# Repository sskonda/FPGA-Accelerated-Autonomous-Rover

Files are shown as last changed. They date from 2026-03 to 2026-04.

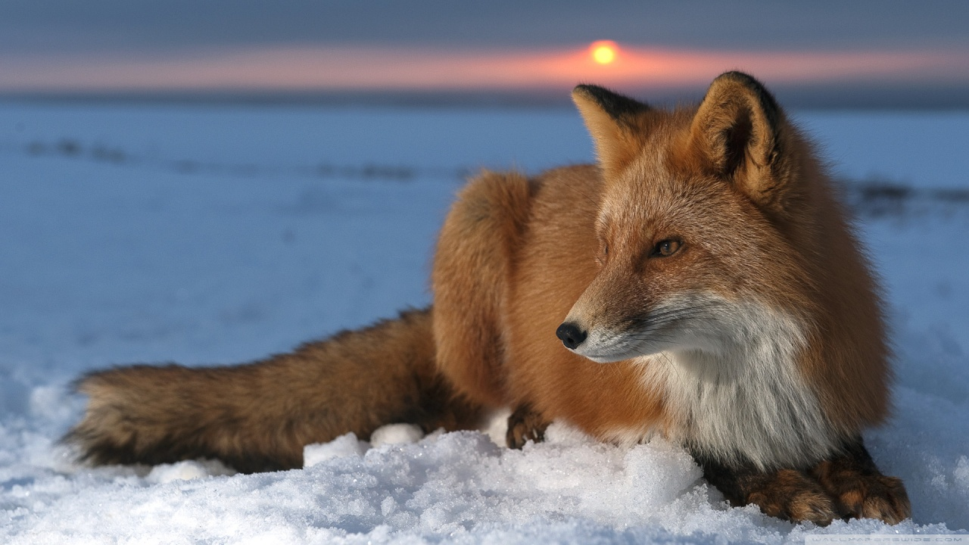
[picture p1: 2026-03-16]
vivado-library-master/ip/video_scaler/hls_src/test/fox.bmp

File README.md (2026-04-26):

# FPGA-Accelerated-Autonomous-Rover

Autonomous FPGA-based mobile robot that follows lanes, detects obstacles, monitors system telemetry, locates a charging dock, and demonstrates wireless charging behavior using a Zynq-based FPGA SoC.

This project is also referred to as **ERN**: **FPGA-Based Electronic Rechargeable Navigator**.

## Table of Contents

- [Project Purpose](#project-purpose)
- [Problem Being Addressed](#problem-being-addressed)
- [Project Overview](#project-overview)
- [Why an SoC Instead of a Microcontroller, Raspberry Pi, or Jetson?](#why-an-soc-instead-of-a-microcontroller-raspberry-pi-or-jetson)
  - [Compared to a Microcontroller](#compared-to-a-microcontroller)
  - [Compared to a Raspberry Pi](#compared-to-a-raspberry-pi)
  - [Compared to a Jetson](#compared-to-a-jetson)
  - [Why the SoC Approach Fits This Rover Best](#why-the-soc-approach-fits-this-rover-best)
  - [Platform Comparison](#platform-comparison)
  - [The Main Engineering Point](#the-main-engineering-point)
  - [Why This Makes the Project More Impressive](#why-this-makes-the-project-more-impressive)
- [Main System Capabilities](#main-system-capabilities)
  - [Implemented or Integrated](#implemented-or-integrated)
  - [Planned or Demonstrated Behavior](#planned-or-demonstrated-behavior)
- [System Architecture](#system-architecture)
- [Hardware/Software Partitioning](#hardwaresoftware-partitioning)
- [Hardware Platform](#hardware-platform)
  - [Main Compute Platform](#main-compute-platform)
  - [Robot Chassis and Drive System](#robot-chassis-and-drive-system)
  - [Sensors and Peripherals](#sensors-and-peripherals)
- [Vivado FPGA Design](#vivado-fpga-design)
- [Embedded Software Architecture](#embedded-software-architecture)
  - [FreeRTOS Task Model](#freertos-task-model)
- [Camera and Video Pipeline](#camera-and-video-pipeline)
- [Line-Following Algorithm](#line-following-algorithm)
  - [HDMI Debug Overlay](#hdmi-debug-overlay)
- [Custom Motor-Control IP](#custom-motor-control-ip)
  - [Register Map](#register-map)
  - [Control Bit Layout](#control-bit-layout)
  - [Differential Drive Usage](#differential-drive-usage)
- [Sensor Integration](#sensor-integration)
  - [BNO055 IMU](#bno055-imu)
  - [INA260 Power Monitor](#ina260-power-monitor)
  - [MAXSONAR Obstacle Sensor](#maxsonar-obstacle-sensor)
- [Obstacle Detection and Safe Stop](#obstacle-detection-and-safe-stop)
- [Audio Feedback System](#audio-feedback-system)
- [Power Monitoring and Wireless Charging](#power-monitoring-and-wireless-charging)
- [Repository Structure](#repository-structure)
- [Important Source Files](#important-source-files)
- [Build Environment](#build-environment)
- [Bring-Up and Test Strategy](#bring-up-and-test-strategy)
  - [1. Video Only](#1-video-only)
  - [2. Motor IP Only](#2-motor-ip-only)
  - [3. BNO055 Only](#3-bno055-only)
  - [4. INA260 Only](#4-ina260-only)
  - [5. Sonar Only](#5-sonar-only)
  - [6. Audio Only](#6-audio-only)
  - [7. FreeRTOS Integration](#7-freertos-integration)
  - [8. Full Robot Test](#8-full-robot-test)
- [Typical UART Output](#typical-uart-output)
- [Engineering Challenges and Fixes](#engineering-challenges-and-fixes)
  - [Camera Pipeline Bring-Up](#camera-pipeline-bring-up)
  - [Vitis and xparameters.h Compatibility](#vitis-and-xparametersh-compatibility)
  - [FreeRTOS and Interrupt Conflicts](#freertos-and-interrupt-conflicts)
  - [Sensor Initialization Blocking](#sensor-initialization-blocking)
  - [UART Logging From Multiple Tasks](#uart-logging-from-multiple-tasks)
  - [Audio Integration](#audio-integration)
  - [Motor Control and Duty Tuning](#motor-control-and-duty-tuning)
- [Current Status](#current-status)
- [Known Limitations](#known-limitations)
- [Future Work](#future-work)
- [Skills Demonstrated](#skills-demonstrated)
- [Team](#team)
- [Project Summary](#project-summary)

## Project Purpose

The purpose of this project is to design and build a small-scale autonomous guided vehicle that demonstrates the value of **FPGA-based real-time control** in an embedded robotics system.

The rover is designed to behave like a simplified autonomous mobile robot used in warehouse, factory, or material-handling environments. It must detect a visual path on the ground, follow that path, stop safely when an obstacle is present, monitor its own electrical state, and eventually navigate toward a charging station when battery level is low.

The important part of this project is not only that the robot can move. The main purpose is to demonstrate a complete **hardware/software co-design** approach:

- Real-time camera and video infrastructure is handled using FPGA-oriented hardware blocks.
- Motor timing is generated deterministically using custom programmable logic.
- High-level behavior, telemetry, task scheduling, and control decisions run on the ARM processor.
- FreeRTOS coordinates multiple concurrent robot subsystems.
- Power, sensing, actuation, perception, audio, and charging are integrated into one platform.

This makes the project more than a basic robotics demo. It is a complete embedded SoC system that combines computer vision, FPGA logic, real-time software, custom hardware IP, sensor integration, and power electronics.

## Problem Being Addressed

Repetitive material-handling tasks in warehouses and factories are commonly automated using autonomous guided vehicles or autonomous mobile robots. These robots transport materials along predefined routes, avoid obstacles, and return to charging stations when power is low.

Many small autonomous robots are built around software-centric platforms such as Raspberry Pi boards, Jetson modules, or microcontrollers. Those platforms are flexible and easy to prototype with, but they often push every major subsystem through software. Camera processing, motor control, telemetry, obstacle detection, audio, and decision logic all compete for CPU time, memory bandwidth, and operating-system scheduling.

That creates several problems:

- **Higher latency** for time-sensitive camera and control tasks
- **Less predictable timing** when multiple software tasks run at once
- **Higher power usage** compared to dedicated hardware logic
- **More CPU contention** between vision, telemetry, control, and I/O
- **Less deterministic motor control** when PWM generation depends on software timing
- **Reduced scalability** when adding more sensors, actuators, or perception features

This project explores a different approach: use an FPGA SoC to separate the system into hardware tasks and software tasks. The FPGA fabric handles deterministic and timing-sensitive work, while the ARM processor handles high-level system behavior.

## Project Overview

The FPGA-Accelerated Autonomous Rover is built around the **Digilent Zybo Z7-20**, which contains a **Xilinx Zynq-7000 SoC**. The Zynq device combines an ARM Cortex-A9 processing system with FPGA programmable logic on the same chip.

The rover uses:

- A **PCam 5C camera** for visual lane detection
- A **Zybo Z7-20 FPGA SoC** for video, control, and peripheral integration
- A **custom AXI4-Lite motor-control IP** for deterministic PWM generation
- A **BNO055 IMU** for motion telemetry and navigation experiments
- An **INA260 power monitor** for voltage/current/power telemetry
- A **MAXSONAR ultrasonic range sensor** for obstacle detection
- The **Zybo onboard SSM2603 audio codec** for audio feedback
- A **wireless charging dock** to demonstrate autonomous recharging behavior

The robot's intended behavior is:

1. Boot the FPGA and embedded software.
2. Initialize the camera, video pipeline, motor IP, sensors, sonar, telemetry, and optional audio.
3. Display live camera output over HDMI.
4. Detect a tape-based lane in the camera frame.
5. Compute the lane center relative to the image center.
6. Adjust left and right motor duty cycles to keep the lane centered.
7. Stop or brake if an obstacle is detected.
8. Monitor battery voltage/current.
9. Navigate toward a charging location or dock when required.
10. Demonstrate wireless charging by measuring a voltage/current increase at the charging location.

## Why an SoC Instead of a Microcontroller, Raspberry Pi, or Jetson?

A major purpose of this project was to demonstrate why a **System-on-Chip FPGA platform** is valuable for real-time embedded robotics. The rover could have been built with a microcontroller, Raspberry Pi, Jetson Nano, or another software-centric embedded computer, but each of those platforms would force a different set of compromises.

The Zybo Z7-20 is built around a Zynq-7000 SoC, which combines two important computing resources on the same chip:

1. **Processing System (PS):** ARM Cortex-A9 processor cores for software, control logic, system initialization, telemetry, and FreeRTOS task scheduling.
2. **Programmable Logic (PL):** FPGA fabric for deterministic hardware acceleration, custom peripherals, video movement, PWM generation, and timing-sensitive interfaces.

That combination is the central reason this project uses an SoC. The robot is not just running code on a processor. It is dividing the system into hardware and software responsibilities.

### Compared to a Microcontroller

A microcontroller would be good for basic motor control, sensor polling, and simple real-time logic. If the project only needed to read a few sensors and drive a few PWM signals, a microcontroller would be simpler, cheaper, and lower power.

However, this rover requires more than simple control. It needs to handle camera input, video frame movement, line detection, motor control, telemetry, obstacle sensing, audio output, and power monitoring at the same time.

A microcontroller would struggle with this system for several reasons:

- It does not have enough memory bandwidth for high-resolution video.
- It usually cannot handle 1920x1080 camera frame buffers directly.
- It has limited RAM compared to the size of full video frames.
- It cannot easily implement custom high-throughput hardware pipelines.
- It would need to time-share the CPU between vision, control, telemetry, and communication.
- Adding more hardware interfaces quickly becomes limited by fixed peripherals.
- Complex video or image-processing tasks would either be too slow or require external hardware.

For example, the rover's camera pipeline uses 1920x1080 RGB frames. A single RGB888 frame is approximately:

```text
1920 * 1080 * 3 bytes = 6,220,800 bytes ≈ 5.93 MiB
```

With triple buffering:

```text
3 * 6,220,800 bytes = 18,662,400 bytes ≈ 17.8 MiB
```

That alone is far beyond what many microcontrollers can comfortably store or process. A microcontroller can control a robot, but it is not the right platform for a robot that combines live video, frame buffering, real-time perception, multiple sensors, and custom hardware control.

In this project, the FPGA SoC solves that problem by allowing the video pipeline and custom motor-control hardware to exist outside the normal CPU execution path.

### Compared to a Raspberry Pi

A Raspberry Pi would be easier to develop on because it can run Linux, OpenCV, Python, ROS, and high-level software tools. It is a strong choice for quick robotics prototyping, networking, and general software development.

However, a Raspberry Pi is still mostly a software-centric platform. The CPU and GPU are powerful, but the system is not designed around user-defined hardware acceleration. For this rover, that creates several disadvantages:

- Camera processing, control logic, telemetry, and I/O compete for CPU time.
- Linux is not naturally deterministic for hard real-time motor-control behavior.
- PWM and timing-sensitive outputs may depend on software, kernel drivers, or external controllers.
- Custom hardware peripherals cannot be added directly into the processor fabric.
- Real-time control can be affected by OS scheduling, background processes, and driver behavior.
- The system does not naturally demonstrate hardware/software co-design.

A Raspberry Pi would make the robot easier to program, but it would also make the project less impressive from an SoC design perspective. The goal of this project was not just to make a robot follow a line. The goal was to build a system where the hardware architecture itself improves timing, modularity, and real-time behavior.

On the Zybo Z7-20, the FPGA fabric can generate motor PWM deterministically while the ARM processor runs FreeRTOS tasks. The video pipeline can continue moving frames through VDMA and HDMI while software reads only the information it needs for control. This separation is much closer to how real embedded vision and industrial control systems are designed.

### Compared to a Jetson

A Jetson Nano or Jetson Orin Nano would be much stronger than a Raspberry Pi for AI inference, GPU acceleration, neural networks, and high-level computer vision. If the main goal were deep-learning-based object detection or neural-network inference, a Jetson would be a very reasonable platform.

However, a Jetson is still primarily a CPU/GPU embedded computer. It accelerates computation using a GPU, but it does not provide the same kind of custom deterministic digital hardware that an FPGA gives.

For this project, the Jetson approach has several drawbacks:

- It is optimized for AI/GPU workloads, not custom motor-control hardware.
- It still relies heavily on software stacks, drivers, CUDA, Linux, and GPU scheduling.
- Deterministic low-level I/O may still require external microcontrollers or motor controllers.
- It consumes more power than is necessary for simple lane following.
- It does not demonstrate custom AXI peripheral design.
- It does not allow the same level of hardware-defined timing and signal control.
- It would make the project more about AI software than SoC hardware/software co-design.

The rover does not need a large neural network to follow a high-contrast tape lane. The more interesting engineering problem is how to move camera data, generate motor signals, read sensors, provide audio feedback, and run real-time tasks in a clean embedded architecture. That is exactly where a Zynq SoC is valuable.

### Why the SoC Approach Fits This Rover Best

The SoC approach is the best fit because this rover has both **high-level software needs** and **low-level deterministic hardware needs**.

The ARM processor handles:

- FreeRTOS task scheduling
- Sensor initialization
- Telemetry output
- Lane-following decision logic
- Obstacle state handling
- Audio state triggers
- Charging state logic
- Debug and runtime control

The FPGA fabric handles or supports:

- Camera data movement
- HDMI video output
- AXI VDMA frame buffering
- Custom motor PWM generation
- AXI memory-mapped peripherals
- Audio hardware interfaces
- Timing-sensitive signal generation
- Future image-processing acceleration

This division is the main architectural strength of the project. Instead of forcing every task through one processor, the system uses the right computing resource for each job.

### Platform Comparison

| Platform | Strengths | Weaknesses for This Project | Why the SoC Is Better Here |
|---|---|---|---|
| Microcontroller | Simple, low power, deterministic, good for basic control | Limited RAM, limited video capability, limited processing throughput, fixed peripherals | The SoC can still do real-time control while also supporting video, DDR frame buffers, custom IP, and hardware acceleration |
| Raspberry Pi | Easy software development, Linux support, OpenCV/ROS support, strong community | Software-centric, less deterministic timing, limited custom hardware integration, CPU/GPU contention | The SoC provides programmable logic for deterministic PWM, hardware video movement, and custom AXI peripherals |
| Jetson | Strong GPU/AI performance, good for neural-network inference and advanced vision | Higher power, Linux/GPU stack complexity, less direct custom hardware control, overkill for tape lane following | The SoC is better for deterministic embedded vision/control without relying on a heavy AI/GPU pipeline |
| Zynq FPGA SoC | ARM processor plus FPGA fabric, custom hardware acceleration, deterministic I/O, AXI integration | More complex development flow, requires Vivado/Vitis knowledge, harder initial bring-up | Best match for demonstrating real hardware/software co-design in an embedded robotics system |

### The Main Engineering Point

The main engineering point of this project is that an autonomous robot is not just a software problem. It is a system-level architecture problem.

A software-only design asks:

```text
How fast can the CPU process everything?
```

This SoC design asks:

```text
Which parts should be hardware, which parts should be software, and how should they communicate?
```

That is the more important question for real embedded systems.

For this rover:

- Motor PWM belongs in hardware because timing should be deterministic.
- Video movement belongs in hardware because frame data is large and continuous.
- Sensor polling belongs in software because it is periodic and easier to debug.
- High-level behavior belongs in software because the robot state machine changes during development.
- Future lane preprocessing can move into hardware because pixel operations are parallel.
- Telemetry belongs in software because it is slow compared to the hardware data path.

This is why the project uses a Zynq SoC. It lets the rover behave like a true embedded hardware/software system instead of a general-purpose computer attached to motors.

### Why This Makes the Project More Impressive

Using an SoC makes the project more technically meaningful because it demonstrates skills that are not shown by a typical Raspberry Pi or Jetson robot.

This project demonstrates:

- Custom AXI peripheral design
- FPGA-based PWM generation
- Processor-to-FPGA memory-mapped control
- MIPI camera integration
- AXI VDMA video buffering
- HDMI video output
- FreeRTOS task scheduling on ARM
- Hardware/software partitioning
- Real-time embedded debugging
- Multi-peripheral system integration
- Sensor and actuator coordination
- Power and charging telemetry
- Full-system robotics architecture

A Raspberry Pi or Jetson implementation could show that the robot works. The Zynq SoC implementation shows how the robot is architected.

That distinction matters. The project is not just a line-following car. It is a demonstration of how an FPGA SoC can be used to build a real-time autonomous embedded system where perception, control, sensing, audio, telemetry, and power management are split across hardware and software in a deliberate way.

## Main System Capabilities

### Implemented or Integrated

- Zybo Z7-20 Zynq-7000 SoC platform
- PCam 5C camera input
- HDMI live video passthrough
- AXI VDMA frame buffering
- Triple-buffered 1920x1080 RGB video frames
- Custom 4-channel AXI4-Lite motor-control IP
- PWM control for four brushed DC motors
- Differential/tank-drive motion control
- FreeRTOS-based multitasking
- BNO055 IMU integration over PS I2C1
- INA260 power-monitoring integration over PS I2C1
- MAXSONAR range sensing through AXI UARTLite
- Obstacle stop behavior
- UART telemetry logging
- Audio feedback through SSM2603 codec, AXI Audio Formatter, and I2S transmitter
- Selectable subsystem test firmware
- Wireless charging dock firmware
- PCB files for charging, power, and peripheral boards

### Planned or Demonstrated Behavior

- Lane following using camera-derived line position
- HDMI debug overlay showing image center and detected lane center
- Safe stop when an obstacle is detected
- Battery voltage/current telemetry
- Charging dock identification
- Wireless charging voltage/current demonstration
- Autonomous state-machine behavior for navigation and charging

## System Architecture

```text
                         +------------------------------------------------+
                         |                Zybo Z7-20 Board                 |
                         |              Xilinx Zynq-7000 SoC               |
                         +------------------------------------------------+
                                             |
                  +--------------------------+--------------------------+
                  |                                                     |
                  v                                                     v
+--------------------------------------+        +--------------------------------------+
| Programmable Logic (FPGA / PL)       |        | Processing System (ARM / PS)        |
+--------------------------------------+        +--------------------------------------+
| MIPI CSI-2 / D-PHY camera pipeline   |        | FreeRTOS scheduler                  |
| AXI VDMA video frame movement        |        | Lane-following control logic        |
| HDMI video output infrastructure     |        | Sensor polling                      |
| Custom motor PWM controller          |        | Obstacle detection state handling   |
| AXI UARTLite for sonar               |        | Telemetry formatting and logging    |
| AXI Audio Formatter and I2S TX       |        | Audio trigger logic                 |
| AXI interconnects and peripherals    |        | High-level robot state machine      |
+--------------------------------------+        +--------------------------------------+
                  |                                                     |
                  +--------------------------+--------------------------+
                                             |
                                             v
                              +------------------------------+
                              |      Rover Hardware Body      |
                              +------------------------------+
                              | PCam 5C camera                |
                              | Four brushed DC motors        |
                              | TB67H450AFNG motor drivers    |
                              | BNO055 IMU                    |
                              | INA260 power monitor          |
                              | MAXSONAR obstacle sensor      |
                              | Speaker / AUX audio output    |
                              | Wireless charging receiver    |
                              +------------------------------+
```

## Hardware/Software Partitioning

A major design goal was to decide which parts of the system should be hardware and which parts should be software.

| Subsystem | Implemented In | Reason |
|---|---|---|
| Video data movement | FPGA fabric / AXI VDMA | High-throughput frame movement is better handled by dedicated hardware |
| HDMI output | FPGA video pipeline | Provides live visual debugging without CPU rendering |
| Motor PWM | Custom FPGA IP | PWM timing should be deterministic and independent of software jitter |
| Motor commands | ARM software | High-level decisions are easier to modify in C/C++ |
| Lane control | ARM software using camera frame data | Current implementation is easier to debug and tune in software |
| Future lane preprocessing | FPGA fabric | Thresholding, filtering, and lane feature extraction can be accelerated |
| IMU telemetry | ARM software over I2C | Sensor setup and polling are manageable in software |
| Power telemetry | ARM software over I2C | Voltage/current reporting is periodic, not cycle-critical |
| Sonar parsing | ARM software over UARTLite | ASCII range frames are simple to parse in software |
| Audio output | FPGA audio IP + ARM control | Audio streaming uses hardware IP while software triggers feedback |
| Robot state machine | ARM software | Behavior logic changes frequently during testing |
| Wireless charging demonstration | Power hardware + ARM telemetry | Charging behavior is verified through monitored voltage/current |

## Hardware Platform

### Main Compute Platform

- **Board:** Digilent Zybo Z7-20
- **SoC:** Xilinx Zynq-7000
- **Processor:** Dual-core ARM Cortex-A9
- **Programmable Logic:** Xilinx 7-series FPGA fabric
- **Development tools:** Vivado 2024.2 and Vitis 2024.2
- **Programming/debug interface:** JTAG and UART through the Zybo PROG UART micro-USB port

### Robot Chassis and Drive System

- **Chassis:** Four-wheel rover chassis based on the OSOYOO FlexiRover-style platform
- **Motors:** Four 6 V brushed DC TT motors
- **Drive style:** Differential / tank drive
- **Motor drivers:** TB67H450AFNG motor-driver modules
- **Control signal style:** PWM plus direction/brake control

Motor channel mapping:

| Motor Channel | Physical Motor |
|---|---|
| Motor 0 | Front left |
| Motor 1 | Back left |
| Motor 2 | Front right |
| Motor 3 | Back right |

### Sensors and Peripherals

| Device | Interface | Purpose |
|---|---|---|
| PCam 5C | MIPI CSI-2 | Camera input for lane following and dock detection |
| BNO055 | PS I2C1 | IMU telemetry and heading/motion experiments |
| INA260 | PS I2C1 | Battery voltage, current, and power telemetry |
| MAXSONAR | AXI UARTLite | Obstacle detection |
| SSM2603 codec | AXI IIC / I2S / Audio Formatter | Audio feedback |
| TB67H450AFNG drivers | FPGA PWM/GPIO-style outputs | Motor actuation |
| Wireless charging receiver | Power board | Charging demonstration |

## Vivado FPGA Design

The Vivado block design combines Digilent's camera/HDMI infrastructure, Xilinx AXI peripherals, and custom motor-control logic.

Major blocks include:

- Zynq7 Processing System
- MIPI CSI-2 receiver
- MIPI D-PHY receiver
- AXI VDMA
- Video timing controller
- Dynamic video clocking
- HDMI output path
- Custom `motor_ctrl_4ch` AXI4-Lite peripheral
- AXI UARTLite for sonar
- AXI Audio Formatter
- I2S Transmitter
- AXI IIC for codec configuration
- AXI GPIO for codec mute control
- AXI interconnects
- Processor system reset blocks
- PS I2C0 for camera configuration
- PS I2C1 for sensor telemetry

The Vivado design went through several incremental versions. The project was built up in phases because adding every subsystem at once makes debugging extremely difficult. The typical progression was:

1. Camera and HDMI passthrough only
2. Camera plus custom motor IP
3. Camera, motor IP, and I2C sensor bus
4. Camera, motor IP, sensors, and sonar UART
5. Audio subsystem added through Audio Formatter and I2S
6. FreeRTOS integration with concurrent tasks
7. Line-following control loop using the video frame buffer

## Embedded Software Architecture

The embedded software runs on the ARM Cortex-A9 processing system. The project uses standalone Vitis applications and FreeRTOS-based applications rather than a full Linux/PetaLinux system for the current integration work.

The software is responsible for:

- Initializing the platform
- Configuring the video pipeline
- Initializing motor-control registers
- Initializing I2C sensors
- Initializing UARTLite sonar
- Initializing the audio codec and audio IP
- Running the FreeRTOS scheduler
- Processing camera frame data
- Computing lane error
- Applying motor commands
- Handling obstacle stop behavior
- Printing telemetry over UART
- Managing robot state

### FreeRTOS Task Model

The integrated robot firmware is organized into multiple FreeRTOS tasks.

| Task | Purpose |
|---|---|
| Logger task | Centralizes UART output so multiple tasks do not directly fight over `xil_printf` |
| Sensor task | Initializes and reads BNO055 and power telemetry |
| Sonar task | Reads and parses MAXSONAR range frames |
| Vision task | Processes camera frame data and updates lane state |
| Motor task | Converts lane/obstacle state into motor-control outputs |
| Telemetry task | Periodically prints runtime state |
| Audio task | Initializes codec/audio path and plays feedback sounds when triggered |

This structure keeps subsystems isolated. If a sensor is unavailable, the rest of the robot can continue running instead of blocking the entire system.

## Camera and Video Pipeline

The video pipeline began from the Digilent Zybo Z7 PCam 5C HDMI passthrough design and was adapted into the autonomous rover system.

The camera pipeline performs the following:

1. Configure the OV5640 camera sensor over PS I2C.
2. Receive image data through MIPI CSI-2 and MIPI D-PHY.
3. Move frames into DDR memory using AXI VDMA.
4. Use multiple frame buffers for stable video movement.
5. Read frames back for HDMI output.
6. Allow software to inspect the frame buffer for line-following logic.
7. Draw debug overlays into the frame buffer so the HDMI output shows internal vision state.

Current frame assumptions:

```text
Resolution:       1920 x 1080
Pixel format:     RGB24
Bytes per pixel:  3
Frame buffers:    3
Base address:     DDR base + 0x0A000000
```

Typical runtime output:

```text
VDMA Frame 0 Addr: 0x0A000000
VDMA Frame 1 Addr: 0x0A5EEC00
VDMA Frame 2 Addr: 0x0ABDD800
```

The HDMI output is important because it provides a live view of what the robot is seeing. It also makes line-following debug much easier because the firmware can draw reference lines directly into the displayed frame.

## Line-Following Algorithm

The current line-following implementation reads from the live video frame buffer and searches for a tape-based lane in the lower part of the image.

The algorithm intentionally stays simple and explainable:

1. Select a region of interest near the bottom of the frame.
2. Sample pixels at a fixed x/y stride.
3. Compute a simple luma/brightness value.
4. Classify pixels as line pixels based on a threshold.
5. Accumulate the x-position of all detected line pixels.
6. Compute the average x-position of the detected line.
7. Compare the detected lane center to the center of the image.
8. Convert the pixel error into a steering correction.
9. Apply different duty cycles to the left and right motors.
10. Draw a visual overlay onto the HDMI output.

Conceptual control logic:

```text
lane_error_px = detected_lane_center_x - image_center_x

steering_delta = lane_error_px * Kp

left_duty  = base_duty + steering_delta
right_duty = base_duty - steering_delta
```

If the detected line is to the right of the image center, the left motors are driven faster than the right motors so the robot steers right. If the line is to the left, the right motors are driven faster than the left motors.

If no valid line is detected, the robot enters a search/stop behavior rather than blindly continuing forward.

### HDMI Debug Overlay

The firmware draws vertical reference lines onto the video stream:

- One line marks the image center.
- One line marks the detected lane center.

This makes it possible to visually confirm whether the robot is correctly detecting the lane and whether the control loop is trying to center the tape in the frame.

## Custom Motor-Control IP

The project includes a custom AXI4-Lite motor controller named `motor_ctrl_4ch`.

This IP exists because motor PWM should not depend on software timing. The ARM processor writes configuration and duty-cycle values over AXI, and the FPGA fabric generates the actual PWM outputs.

### Register Map

```text
Offset  Register      Description
0x00    REG_CTRL      Enable, direction, and brake bits
0x04    REG_PERIOD    PWM period
0x08    REG_DUTY0     Motor 0 duty cycle
0x0C    REG_DUTY1     Motor 1 duty cycle
0x10    REG_DUTY2     Motor 2 duty cycle
0x14    REG_DUTY3     Motor 3 duty cycle
```

### Control Bit Layout

```text
Enable bits:     [3:0]
Direction bits:  [7:4]
Brake bits:      [11:8]
```

Each motor channel supports:

- Enable
- Direction
- Brake
- Independent duty cycle

This allows the rover to control all four motors independently while keeping the PWM timing deterministic.

### Differential Drive Usage

The robot is controlled as a differential-drive vehicle:

- Motors 0 and 1 are the left side.
- Motors 2 and 3 are the right side.
- Steering is performed by changing the relative duty cycle between the two sides.

Example behavior:

```text
Drive straight: left duty ~= right duty
Turn right:     left duty > right duty
Turn left:      right duty > left duty
Stop:           all duties = 0
Brake:          brake bits asserted
```

## Sensor Integration

### BNO055 IMU

The BNO055 is connected to PS I2C1. It is used for motion telemetry and navigation experiments.

The firmware initializes the BNO055 by:

1. Waiting for the sensor to boot.
2. Reading the chip ID.
3. Switching to configuration mode.
4. Setting power mode.
5. Selecting units.
6. Switching into the desired operating mode.
7. Periodically reading acceleration and gyroscope data.

The IMU is useful for:

- Heading estimation
- Straight-line correction experiments
- Motion telemetry
- Square-path navigation tests
- Detecting drift or unexpected motion

### INA260 Power Monitor

The INA260 shares PS I2C1 with the BNO055 and is used to monitor the robot's electrical state.

It provides:

- Bus voltage
- Current
- Power

This is especially important for the wireless charging demonstration. When the robot reaches the charging dock, the system can observe battery voltage/current behavior to verify that charging is occurring.

### MAXSONAR Obstacle Sensor

The sonar sensor is connected through AXI UARTLite. It sends ASCII range frames, which are parsed by the sonar task.

The firmware reads frames in the format:

```text
R###\r
```

The parsed range is converted into inches and compared against a stop threshold.

Typical stop threshold:

```text
SONAR_STOP_INCHES = 18
```

## Obstacle Detection and Safe Stop

Obstacle detection is safety-critical because the robot should not continue driving if something is directly in its path.

The behavior priority is:

1. **Obstacle stop**
2. **Lane following**
3. **Search/hold if no lane is found**

The motor task gives obstacle detection the highest priority. If sonar reports an obstacle inside the stop threshold, the robot brakes regardless of the lane-following result.

Conceptual logic:

```text
if obstacle_detected:
    brake_all_motors()
    mode = OBSTACLE_STOP
else if lane_valid:
    follow_lane()
    mode = FOLLOWING
else:
    brake_all_motors()
    mode = SEARCHING
```

This is an important design point because the robot should fail safely. Losing the line or detecting an obstacle should not cause uncontrolled motion.

## Audio Feedback System

The rover includes an audio feedback system using the Zybo Z7 onboard audio path.

The final audio direction uses:

- SSM2603 codec
- AXI IIC for codec configuration
- AXI GPIO for mute control
- AXI Audio Formatter
- I2S Transmitter
- 12.288 MHz audio master clock
- 48 kHz sample rate

The purpose of audio is to provide audible feedback for robot states such as:

- Startup complete
- Obstacle detected
- System alert
- Charging event
- Test mode selected
- Debug tone or melody playback

The audio subsystem went through several iterations. Early testing explored direct I2S and DMA-style playback. The more stable design uses the Xilinx Audio Formatter with I2S TX. The firmware also uses bounded-timeout codec writes so the audio task cannot hang forever if codec I2C communication fails.

## Power Monitoring and Wireless Charging

The robot includes a wireless charging demonstration subsystem. The goal is to show that the robot can stop at a designated charging location and observe charging behavior through measured voltage/current telemetry.

The charging system includes:

- A charging station with a transmit-side coil and resonator
- A receive-side coil mounted on the robot
- Battery charging and management circuitry
- Power conversion circuitry
- INA260 telemetry for voltage/current/power observation
- Dock firmware and PCB files

The intended full behavior is:

1. Robot follows its lane or route.
2. Robot monitors battery state.
3. Low battery triggers a dock-seeking behavior.
4. Robot identifies the charging station using markers or a known route.
5. Robot aligns with the charging location.
6. Robot stops at the dock.
7. Wireless charging begins.
8. Voltage/current telemetry confirms the charging state.

## Repository Structure

```text
FPGA-Accelerated-Autonomous-Rover/
├── Charging_Dock_Firmware/
│   └── Firmware for the wireless charging dock controller
│
├── Data_Sheets/
│   └── Datasheets for major ICs, modules, boards, sensors, and power components
│
├── HDMI_Camera_Passthrough/
│   └── Camera and HDMI passthrough project files
│
├── PCB_Files/
│   └── PCB design files for power, charging, and peripheral boards
│
├── Source_Files_for_Vitis/
│   └── Embedded C/C++ firmware, subsystem tests, and FreeRTOS integration code
│
├── Useful_bitstreams/
│   └── Known-good FPGA bitstreams for different hardware configurations
│
├── vivado-library-master/
│   └── Digilent/Vivado library assets used by the video/camera design
│
├── How to Fix PCAM vitis code.md
│   └── Notes for adapting and fixing PCam-related Vitis code
│
└── README.md
```

## Important Source Files

Representative firmware and support files include:

| File | Purpose |
|---|---|
| `rtos_line_follow_debug.cc` | FreeRTOS line-following application with video, sonar, BNO055 telemetry, motor control, and HDMI overlay |
| `RTOS_test_no_audio.cc` | FreeRTOS integration test without audio |
| `audio_rtos_tests.cc` | FreeRTOS integration test with audio initialization and beep playback |
| `rtos_square_path.cc` | Square-path navigation experiment using IMU, sonar, and motor control |
| `main.cc` | Earlier standalone camera/video passthrough or integration source |
| `main.c` | Selectable subsystem test firmware |
| `motor_ctrl_4ch.h` | Software driver header for the custom motor-control IP |
| `motor_ctrl_4ch.c` | Motor-control IP driver source |
| `motor_ctrl_4ch_selftest.c` | Register read/write self-test for the motor-control IP |
| `xparams_compat.h` | Compatibility header for SDT-style `xparameters.h` differences |
| `assert_filename_fix.h` | Build compatibility helper |
| `OV5640.h/.cpp` | OV5640 camera configuration support |
| `AXI_VDMA.h` | C++ wrapper for the Xilinx AXI VDMA driver |
| `PS_IIC.h` | PS I2C driver wrapper |
| `PS_GPIO.h` | PS GPIO driver wrapper |
| `ScuGicInterruptController.h` | GIC interrupt-controller wrapper |

## Build Environment

This project was developed using:

- **Vivado:** 2024.2
- **Vitis:** 2024.2
- **Target board:** Digilent Zybo Z7-20
- **Target SoC:** Xilinx Zynq-7000
- **Firmware style:** Standalone and FreeRTOS Vitis applications
- **Programming method:** JTAG through the Zybo PROG UART micro-USB port
- **Debug terminal:** UART console through PuTTY or equivalent serial terminal

## Bring-Up and Test Strategy

The project was brought up incrementally because the complete system contains many interacting peripherals. Testing each block independently made it easier to isolate hardware, Vivado, Vitis, and runtime problems.

Recommended bring-up order:

### 1. Video Only

- Confirm PCam 5C is detected.
- Confirm OV5640 camera configuration over I2C.
- Confirm HDMI output.
- Confirm AXI VDMA frame addresses.
- Confirm stable live video.

### 2. Motor IP Only

- Confirm the custom AXI motor IP appears in `xparameters.h`.
- Confirm the base address matches Vivado Address Editor.
- Write the PWM period register.
- Test one motor channel at a time.
- Verify forward, reverse, stop, and brake behavior.
- Confirm TB67H450AFNG wiring and motor polarity.

### 3. BNO055 Only

- Confirm PS I2C1 wiring.
- Confirm the BNO055 chip ID.
- Confirm acceleration and gyroscope reads.
- Verify that the sensor does not block the scheduler if unavailable.

### 4. INA260 Only

- Confirm shared I2C1 bus behavior.
- Confirm manufacturer and die ID reads.
- Confirm bus voltage, current, and power readings.
- Verify telemetry during charging tests.

### 5. Sonar Only

- Confirm AXI UARTLite base address.
- Confirm UARTLite self-test.
- Confirm ASCII range frame parsing.
- Confirm obstacle threshold behavior.

### 6. Audio Only

- Confirm audio master clock.
- Confirm mute GPIO.
- Confirm codec I2C writes.
- Confirm I2S TX setup.
- Confirm Audio Formatter setup.
- Confirm tone or jingle playback.
- Confirm bounded-timeout behavior prevents lockups.

### 7. FreeRTOS Integration

- Start with logger and one subsystem.
- Add sensor task.
- Add sonar task.
- Add motor task.
- Add telemetry task.
- Add vision task.
- Add audio task only after the core runtime is stable.
- Monitor stack high-water marks and heap usage.

### 8. Full Robot Test

- Confirm video passthrough.
- Confirm HDMI overlay.
- Confirm lane center detection.
- Confirm motor response.
- Confirm obstacle stop.
- Confirm telemetry.
- Confirm charging/power telemetry.
- Confirm audio feedback.

## Typical UART Output

Example output from the integrated FreeRTOS line-following application:

```text
========================================
FreeRTOS line-following robot
Video base  = 0x0A000000 (3 frames, RGB24 1920x1080)
Motor base  = 0x43C50000
UARTLite    = 0x42C00000
[video] passthrough init ok
[rtos] starting scheduler
[sensor] init start
[sonar] init start
[motor] init start
[vision] detection active, overlay visible on HDMI
[motor] line-follow control active
```

Example telemetry output:

```text
[telemetry] video=1 bno=1 sonar=1 lane=1 center=944 err=-16 hits=120 mode=FOLLOW left=692 right=708 range=31 in
```

The runtime telemetry is useful because it shows whether each major subsystem is alive:

```text
video = video passthrough initialized
bno   = BNO055 telemetry available
sonar = sonar range frames being received
lane  = valid lane currently detected
err   = lane offset from image center
mode  = robot drive state
left  = left-side motor duty
right = right-side motor duty
range = sonar distance
```

## Engineering Challenges and Fixes

### Camera Pipeline Bring-Up

The camera pipeline required combining the PCam 5C, MIPI CSI-2, D-PHY, VDMA, dynamic video clocking, and HDMI output path. The initial goal was to reproduce the Digilent passthrough behavior, then integrate that pipeline into the larger robot system.

Important lessons:

- The video pipeline must be stable before adding robot-control logic.
- Frame buffer addresses are one of the first things to verify.
- HDMI output is extremely useful for debugging perception.
- The software must respect the actual frame format and stride.
- Cache coherency matters when software modifies frame buffers that VDMA reads.

### Vitis and `xparameters.h` Compatibility

Some Digilent example code expected classic `xparameters.h` macro names, while newer Vitis/SDT-style platforms may generate different names. The `xparams_compat.h` helper was added to map missing or renamed macros so older-style code could build against the generated platform.

This reduced friction when integrating Digilent camera code with newer Vitis-generated BSP/platform files.

### FreeRTOS and Interrupt Conflicts

One of the major stability issues was getting the video stack and FreeRTOS runtime to coexist. The video demo code and the FreeRTOS Zynq port both interact with interrupt-controller setup. If the video pipeline leaves certain interrupts active while FreeRTOS is taking over scheduling, the runtime can become unstable.

The practical fix was to keep the video passthrough running in hardware while masking or disabling live PL-to-PS video interrupt sources before handing control to FreeRTOS. This allowed the camera/HDMI path to continue while the robot tasks ran under the scheduler.

### Sensor Initialization Blocking

Early versions of the firmware could block forever if a sensor did not ACK on I2C. This is dangerous in a robot runtime because one missing or disconnected device should not prevent the entire system from booting.

The better pattern is:

- Try initialization a bounded number of times.
- Mark the sensor unavailable if initialization fails.
- Continue running the rest of the system.
- Print telemetry showing which subsystem is unavailable.

This approach makes the robot more fault-tolerant during hardware bring-up.

### UART Logging From Multiple Tasks

Direct `xil_printf` calls from multiple FreeRTOS tasks can make logs unreadable and can create debugging confusion. The integrated firmware uses a logger task and log queue so most runtime messages pass through a centralized print path.

This improves:

- UART readability
- Task isolation
- Debug consistency
- Runtime stability

### Audio Integration

Audio integration was challenging because it involved the SSM2603 codec, I2C configuration, mute control, clocking, I2S TX, and Audio Formatter behavior.

Important fixes included:

- Using AXI Audio Formatter with I2S TX
- Providing a 12.288 MHz audio master clock for 48 kHz audio
- Carefully controlling codec mute
- Avoiding unbounded I2C waits
- Using bounded-timeout codec register writes
- Avoiding direct UART prints from the audio task

### Motor Control and Duty Tuning

Motor behavior depends heavily on the physical chassis, motor friction, battery voltage, floor surface, and wheel slip. The motor controller supports independent channel duty values, but the actual line-following behavior requires tuning:

- Base duty
- Minimum duty
- Maximum duty
- Steering proportional gain
- Direction polarity
- Brake behavior
- Left/right motor balance

The project uses configurable constants for these values so the rover can be tuned quickly during testing.

## Current Status

The current project status includes:

- Camera passthrough working through PCam 5C and HDMI
- VDMA frame buffering working with 1920x1080 RGB frames
- Custom motor-control IP integrated and tested
- FreeRTOS runtime integrated with multiple tasks
- Line-following firmware implemented using frame-buffer analysis
- HDMI debug overlay implemented
- BNO055 telemetry integrated
- INA260 power monitoring integrated in test firmware
- Sonar-based obstacle detection implemented
- Audio subsystem tested through Audio Formatter and I2S
- Wireless charging dock firmware and PCB files included
- Multiple subsystem test files available for bring-up and debugging

## Known Limitations

This is an active senior design project, so some parts are still experimental or hardware-dependent.

Known limitations:

- The current lane-detection algorithm depends on lighting, floor color, tape contrast, and camera angle.
- The line-following algorithm is currently simple threshold-based detection.
- More image preprocessing could be moved into FPGA fabric in future revisions.
- Dock detection may require additional AprilTag or visual-marker logic.
- Wireless charging depends heavily on coil alignment and power-board behavior.
- Vitis projects may require local path or platform adjustments after cloning.
- Hardware base addresses can change if the Vivado block design changes.
- Some source files are subsystem tests rather than one final application.
- Full autonomous low-battery docking behavior is still a future integration goal.

## Future Work

Planned improvements include:

- Move more image preprocessing into FPGA fabric.
- Add a cleaner lane-feature extraction hardware block.
- Improve lane detection under different lighting conditions.
- Add adaptive thresholding for tape detection.
- Add AprilTag or visual-marker dock identification.
- Implement a complete dock approach and alignment state machine.
- Use INA260 telemetry for battery-state estimation.
- Add low-battery behavior that triggers autonomous docking.
- Improve closed-loop heading correction using the BNO055.
- Add QSPI boot support for power-on autonomous startup.
- Clean up source organization into reusable drivers and application layers.
- Add more complete Vivado reconstruction documentation.
- Add final demo videos and system diagrams.
- Add measured timing, latency, and power results.

## Skills Demonstrated

This project demonstrates:

- FPGA/SoC hardware/software co-design
- Zynq-7000 Processing System and Programmable Logic integration
- Vivado block design development
- Vitis embedded software development
- AXI4-Lite custom IP development
- Memory-mapped peripheral control
- Deterministic PWM generation in FPGA fabric
- MIPI camera integration
- HDMI video output
- AXI VDMA frame buffering
- FreeRTOS task design
- Embedded C/C++ firmware development
- I2C, UART, GPIO, I2S, and DMA-style peripheral integration
- Sensor bring-up and debugging
- Audio codec configuration
- Real-time telemetry logging
- Robotics control logic
- Obstacle detection and safe-stop behavior
- PCB-level system integration
- Wireless charging demonstration
- Incremental hardware/software validation
- Debugging with UART traces and hardware isolation tests

## Team

**Team Name:** Justice League

- **Sanat Konda**
- **Ryan Robinson**

University of Florida  
Electrical and Computer Engineering  
EEL 4924 Senior Design

## Project Summary

The FPGA-Accelerated Autonomous Rover is a complete embedded robotics system built around a Zynq FPGA SoC. It combines live video, custom motor-control hardware, FreeRTOS-based software, sensor telemetry, obstacle detection, audio feedback, and wireless charging into one autonomous mobile robot platform.

The project demonstrates the core idea of hardware/software co-design: not every task should be forced through software. Timing-sensitive and deterministic functions are better placed in FPGA fabric, while high-level robot behavior is better handled by software running on the ARM processor.

This makes the rover a practical demonstration of SoC architecture, embedded robotics, custom FPGA peripherals, real-time software, and full-system integration.

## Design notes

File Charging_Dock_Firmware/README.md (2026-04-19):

# Charging Dock Firmware

Production-style Raspberry Pi Pico SDK firmware for a wireless charging dock controller with a HIP4080A full bridge, potentiometer tuning, one-button UI, leaf-switch safety interlock, and an SH1106 128x64 SPI OLED front panel.

## Pin map

### Inverter / bridge control

- `HEN` -> `GP10`
- `DIS` -> `GP11`
- `IN+` -> `GP12`
- `IN-` -> `GP13`

### SH1106 OLED over SPI

- `CLK` -> `GP18`
- `MOSI` -> `GP19`
- `DC` -> `GP20`
- `RES` -> `GP21`
- `CS` -> `GP17`

### Inputs

- Pushbutton -> `GP16`
- Potentiometer -> `GP26` / `ADC0`
- Leaf switch -> `GP15`

## Button actions

- Single press: lock or unlock frequency
- Double press: start when allowed, stop when active
- Long press: immediate shutdown

## Application states

- `BOOT`: splash screen, inverter forced off
- `OFF`: unlocked idle state
- `TUNING`: unlocked and pot recently moving
- `LOCKED`: frequency locked, robot absent
- `READY`: frequency locked, robot present, ready to run
- `ACTIVE`: inverter enabled and driven from hardware PWM
- `BLOCKED`: start request denied because the leaf interlock is open
- `FAULT`: emergency shutdown or interlock loss while active

## Global configuration variables in `config.c`

These are the primary board and behavior settings exposed as globals:

- `g_freq_min_hz`
- `g_freq_max_hz`
- `g_default_freq_hz`
- `g_hen_active_level`
- `g_dis_active_level`
- `g_button_active_level`
- `g_leaf_active_level`
- `g_sh1106_col_offset`
- `g_ui_redraw_ms`
- `g_input_scan_ms`
- `g_double_click_ms`
- `g_long_press_ms`
- `g_pot_filter_shift`
- `g_pot_hysteresis_counts`
- `g_ui_anim_tick_ms`

## Remaining compile-time constants in `config.h`

These are still centralized in one place but left as compile-time constants:

- GPIO pin assignments
- SH1106 SPI port and baud rate
- splash, blocked, and fault hold durations
- the SH1106 framebuffer geometry
- `IN+` / `IN-` active and idle levels

`HEN` and `DIS` polarity often needs board-specific adjustment depending on the HIP4080A front-end wiring. `IN+` and `IN-` idle and active levels are also centralized in `config.h` for the same reason.

The SH1106 visible column alignment may vary slightly by panel. If text looks shifted, tune `g_sh1106_col_offset` in `config.c`.

## Build with Pico SDK

Requirements:

- a working Pico SDK checkout that contains `pico_sdk_init.cmake`
- GNU Arm Embedded toolchain with `arm-none-eabi-gcc`
- CMake
- a generator such as Ninja or a configured VS Code Pico environment

Build:

```powershell
cmake -S . -B build -DPICO_BOARD=pico2_w
cmake --build build
```

Expected firmware image:

```text
build/charging_dock_firmware.uf2
```

## Flashing

1. Hold the Pico `BOOTSEL` button while connecting USB.
2. Wait for the `RPI-RP2` mass-storage device to appear.
3. Copy `build/charging_dock_firmware.uf2` onto that drive.
4. The board reboots automatically and starts the dock controller firmware.

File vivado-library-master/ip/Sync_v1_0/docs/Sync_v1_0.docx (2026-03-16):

# 1 Introduction

IP quick facts
Supported device families | Zynq®-7000, 7 series
Supported user interfaces | N/A

Provided with core
Design files | VHDL
Simulation model | VHDL Behavioral
Constraints file | XDC
Software driver | N/A

Tested design flows
Design entry | Vivado™ Design Suite 2015.3
Synthesis | Vivado Synthesis 2015.3

This user guide describes the Digilent Sync Intellectual Property. This IP provides clock domain crossing for signals where variable crossing latency does not affect functionality.

# 2 Features

- Brings global reset into a local clock domain where reset has to be synchronously de-asserted
- Brings asynchronous signal into a synchronous domain

# 3 Performance

No clock constraints are defined in this IP. Maximum frequency depends on the switching performance of flip-flops and the IP should not be the limiting factor in timing closure.

The IP properly defines false path constraints between source and destination clock domains.

# 4 Use cases

Figure 1. Sync internal diagram

The IP instantiates flip-flops and forms a chain that passes the input signal (iIn) towards the output (oOut). The first flip-flop is optional and works on the input (source) clock domain. It re-registers the input to make sure the downstream synchronizer chain has a glitch-free input. All the other flip-flops work on the output (destination) clock domain and each lowers the chance of failure due to metastability by increasing the time available for these events to settle. The number of synchronizer stages can be customized in the IP configuration wizard.

## Local reset

Consider a global reset signal that is asynchronous to a local clock domain you wish to reset. Depending on the application it might be important to de-assert the reset synchronous to the local clock, so that it can be guaranteed that all circuits come out of reset simultaneously. Reset assertion remains asynchronous, which is useful in cases where the local clock can be stopped.

Specify the correct polarity for the input reset signal in IP configuration and tie it to the aRst or aRst_n pin. Configure the output reset value to 0 or 1, depending on the desired polarity of the output reset signal. The input pin iIn should be tied to the constant inactive value of the output reset. Re-registering iIn is not required in this use case.

## Asynchronous input

Any input signal asynchronous to circuits it is connected to has the chance to become metastable. Using synchronizers lowers the chance of failure significantly. If the source clock of the input is known (synchronous to a known clock domain), tick “Re-register input on its source domain” and connect the source clock to InClk. If the source clock is not available, disable this option. Connecting a reset is optional and can be left unconnected.

# 5 Port Descriptions

Signal Name | Interface | Signal Type | Init State | Description
aRst(_n) | - | I | N/A | Asynchronous reset of configurable polarity. Optional
InClk | - | I | N/A | Source clock for iIn. Optional
OutClk | - | I | N/A | Destination clock for oOut.
iIn | - | I | N/A | Input signal to be synchronized.
oOut | - | O | configurable | Input iIn synchronized to OutClk.

Table 1. Port descriptions.

# 6 Designing with the core

## Customization

The IP provides four customizable parameters: the polarity of reset signal, the reset value of oOut, option to re-register iIn, and the number of synchronizer stages to use.

Copyright Digilent, Inc. All rights reserved. Other product and company names mentioned may be trademarks of their respective owners. Page 2 of 3

DOC#: 516-003 Copyright Digilent, Inc. All rights reserved. Other product and company names mentioned may be trademarks of their respective owners. Page 1 of 3

Sync 1.0 IP Core User Guide

1300 Henley Court Pullman, WA 99163 509.334.6306 www.digilentinc.com Sync 1.0 IP Core User Guide Revised October 7, 2016; Author Elod Gyorgy

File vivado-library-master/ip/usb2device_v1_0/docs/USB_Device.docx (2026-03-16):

!*!*Under development*!*!

Please note that this version of the IP core is not a final one, but still currently under development. This notice will be removed once the IP core is in a stable/final state.

# 1 Introduction

IP quick facts
Supported device families | Zynq®-7000, 7 series
Supported user interfaces | Xilinx®: AXI4, AXI4 Lite, ULPI

Provided with core
Design files | VHDL
Simulation model | -
Constraints file | XDC
Software driver | N/A

Tested design flows
Design entry | Vivado™ Design Suite 2015.4
Synthesis | Vivado Synthesis 2015.4

This user guide describes the Digilent USB Device Controller Intellectual Property. This IP is designed to provide communication between an AXI Microblaze system and a USB 2.0 Host.

# 2 Features

- Capable to operate at 480Mb/s (USB High Speed)
- ULPI Interface
- tested with 2 endpoints
- Integrated DMA engine

# 3 Overview

The design is divided in two clock domains. The logic on the ULPI clock side is responsible with the UPLI bus decoding, speed negotiation and packet decoding. The logic on the AXI side is responsible for transferring data between the transmit buffers, receive buffers, context and the main memory.

Figure 1. IP top-level diagram.

## Protocol Engine

This block is responsible with managing communication on the ULPI bus, with speed negotiation and with packet encoding/decoding.Transmit packet data is passed to the Protocol Engine block through the TX Buffers, while received packets are placed in the RX Buffers.

#### 3.1.1 ULPI

The ULPI block decodes the data received over the ULPI bus and implements the required frameworks for NOPID, Transmit packet (PID), Register write (REGW) and register read (REGR) commands. According to the ULPI specifications, the USB PHY can abort packets that are being transmitted. This requirement is not implemented yet.

#### 3.1.2 High Speed Negotiation

This block implements the logic required for carrying out the High Speed Negotiation, Reset, Suspend and Resume as described by Chapter7 of the USB Specifications. Suspend and Resume have not been tested yet.

#### 3.1.3 Protocol Engine

This block implements Chapter8 (Protocol Layer) of the USB specifications. The implemented and tested state machines are Dev_Do_BCINTI, Dev_HS_BCO. Dev_HS_Ping, Dev_Do_BCINTO are not tested. Isochronous transfers are not supported. Handshake responses are generated automatically.

#### 3.1.4 Transmit Buffers

Data is passed from the DMA engine to the Protocol Engine in two stages. Packets are first stored into an AXI Stream interface FIFO. The second stage is implemented into a dual port BRAM block. Each endpoint has 1024 bytes reserved and the internal logic is responsible with distributing data from the TX FIFO to the correct address in BRAM. The transmit buffers are implemented in the Transmit_Path module

#### 3.1.5 Receive Buffers

The received packet bytes are stored as they arrive in an input buffer. If the packet is received without errors it is passed to an AXI Stream interface FIFO. If errors are detected, the packet is discarded. There is no need for individual buffers for each endpoint since the DMA engine will distribute the packets to the endpoint buffers allocated in system memory. The receive buffer is placed in the top module.

## 3.2 Context

There are two data structures that provide the information required to transfer data between the ULPI interface and the system memory. These two structures are the Queue Heads (dQH) and the Transfer Descriptors (dTD). The software is responsible for creating both Queue Heads and Transfer Descriptors in system memory and the device controller will fetch a “copy” of each. For more information see 5.3 Device Data Structures.

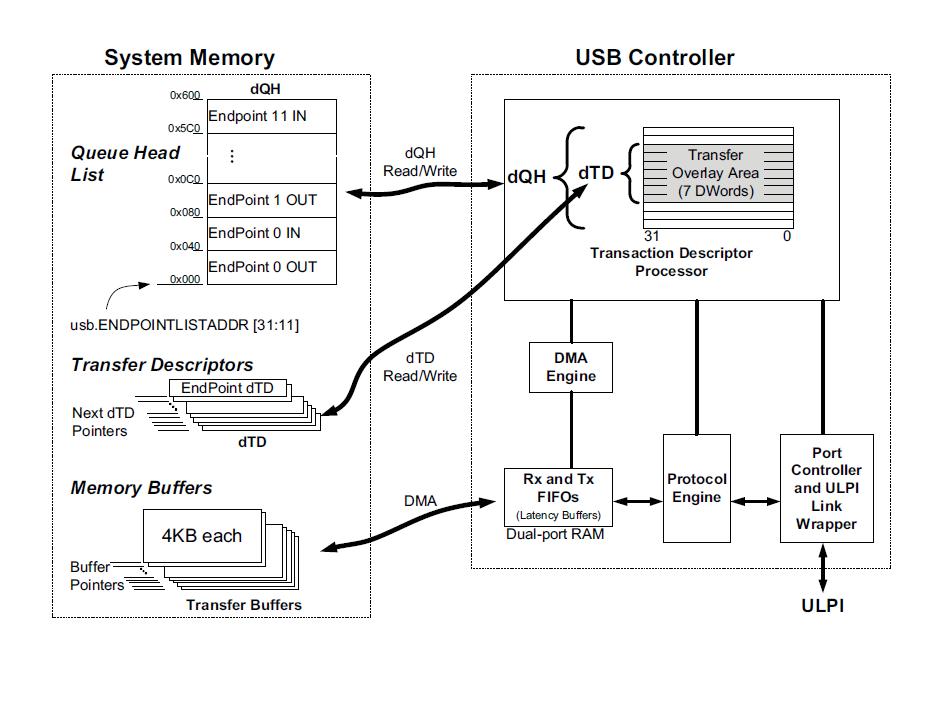
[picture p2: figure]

Figure 2. Device Descriptors.

### 3.3 DMA Transfer Manager

The DMA Transfer Manager block holds the state machines that control the DMA engine. There are four “frameworks” implemented in this block: one responsible for priming endpoints, one for control transfers, one for input packets and one for output packets. Both control information (Context memory) and packet data need to be transferred for each sequence. For a more detailed description refer to section 5.4 Device Frameworks

### 3.4 Control Registers

All control registers are implemented in this block. The processor can read and write registers through an AXI Lite interface.

# 4 Interface Descriptions

The interfaces of the Device Controller Core are listed and described in Table 1.

Interface Name | Interface | Signal Type | Init State | Description
AXI4 Lite | Slave | - | N/A | The AXI4 Lite interface is used to control register access.
AXI4 | Master | - | N/A | The AXI4 master interface is used by the DMA engine to transfer data between the device controller and the system memory.
ULPI | Slave | - | N/A | See UTMI+ Low Pin Interface (ULPI) Specification, Revision 1.1, October 20th, 2004

Table 1. Port descriptions.

# 5 Hardware Description

## Interrupts

The Status register (USBSTS) and the Interrupt Enable register (USBINTR) are responsible for triggering interrupts. There are 6 interrupt conditions currently supported by the controller:

1. UI: Set when a transfer is completed. (Bit 0 in USBSTS)
2. NAKI: Set when a device has generated a NAK. (Bit 16 in USBSTS)
3. SLI: Set when the device enters suspend state. (Bit 8 in USBSTS)
4. SRI: Set when a Start of Frame (SOF) packet is received. (Bit 7 in USBSTS)
5. URI: Set when Reset is detected. (Bit 6 in USBSTS)
6. PCI: Port Change Detect. (Bit 2 in USBSTS)

## Endpoint Registers

ENDPTSETUPSTAT: Bits[11:0] are set when the corresponding endpoint receives a setup packet. The access type for this register is write-one-to-clear.

ENDPTPRIME: Bits [27:16] are relevant for IN endpoints while bits [11:0] are relevant for OUT endpoints. Software sets a bit to instruct the controller to fetch the corresponding queue head, transfer descriptor and packet data from the main memory. The access type for this register is write-one-to-set. Hardware automatically clears the corresponding bits when the prime operation is complete.

ENDPTFLUSH: Bits [27:16] are relevant for IN endpoints while bits [11:0] are relevant for OUT endpoints. Software sets a bit to instruct the hardware to flush the corresponding endpoint. The access type for this register is write-one-to-set. Hardware automatically clears the corresponding bits when the flush operation is complete.

ENDPTSTAT: Bits [27:16] are relevant for IN endpoints while bits [11:0] are relevant for OUT endpoints. Hardware sets a bit when the corresponding endpoint has been primed. The access type for this register is read only.

ENDPTCOMPLETE: Bits [27:16] are relevant for IN endpoints while bits [11:0] are relevant for OUT endpoints. Hardware sets a bit to indicate that the corresponding endpoint has completed the transfer that was primed.

ENDPTCTRL{11:0}: Bits [19:18] are relevant for IN endpoints while bits [3:2] are relevant for OUT endpoints. This register is used to select the endpoint type. Isochronous endpoints are not supported. The access type for this register is read-write.

## Device Data Structures

The processor does not directly instruct the DMA engine what data and where to/from to transfer it. Instead, it allocates space in system memory in order to define data structures (Queue Heads and Transfer Descriptors) that describe each individual transfer. Each endpoint has one corresponding Queue Head structure (Fig) and a linked list of Transfer Descriptors. The Device controller first fetches the Queue Head. Afterwards, based on the information specified in the Queue Head, the device controller fetches the first transfer descriptor and copies it into the Context memory in the Overlay Area of the corresponding endpoint.

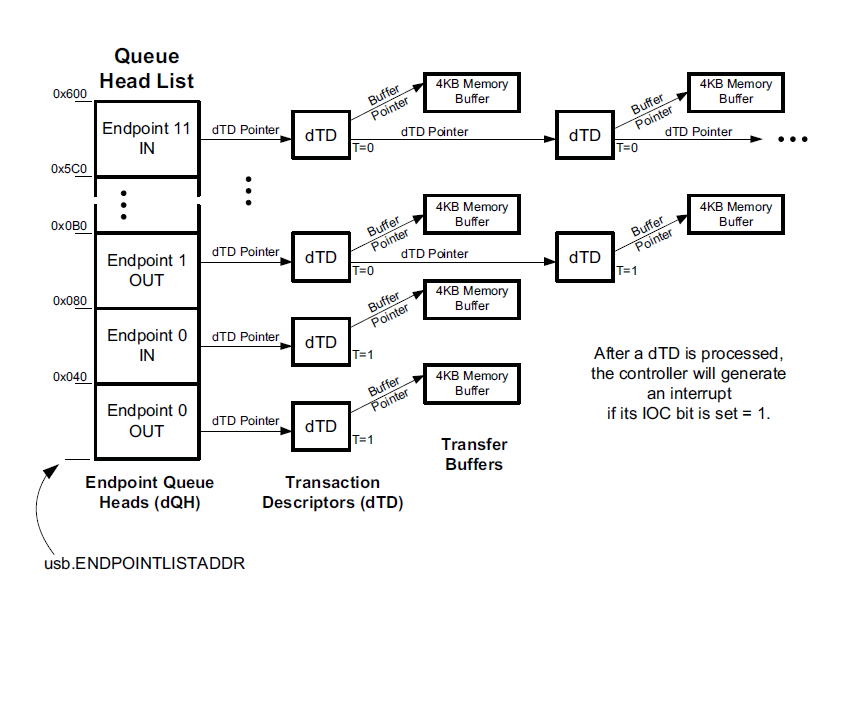
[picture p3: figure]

Figure 1. Device Link List example.

### Queue Heads (dQH)

The Maximum Packet Length field stores the maximum packet length for each individual endpoint.

The Setup Buffer Bytes 3…0 and Setup Buffer Bytes 7…4 store setup packets received. Setup packets are always 8 byte long and reading this fields in the Queue head is the only mean by which software can access setup data.

Software is also responsible to write the Next dTD Pointer field with the address of the first Transfer Descriptor.

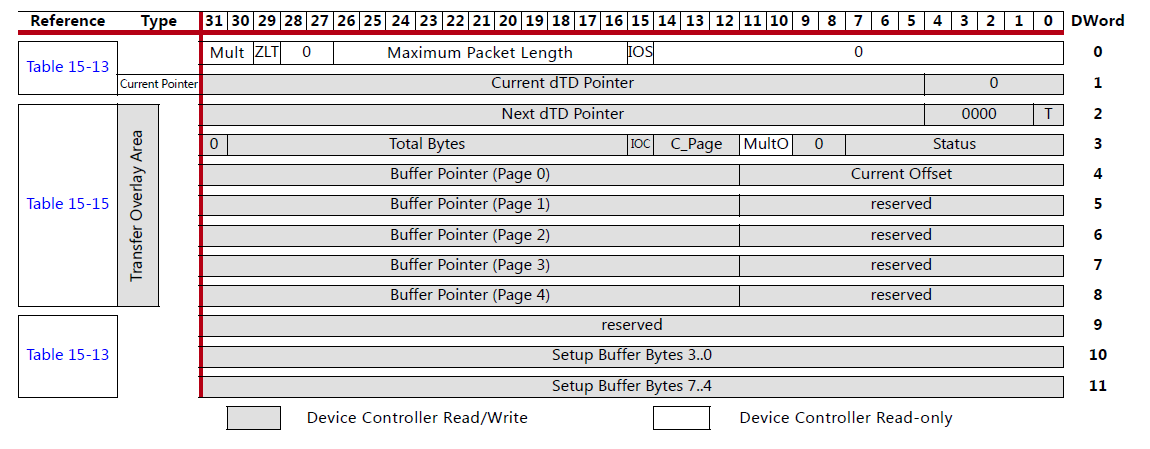
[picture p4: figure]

Figure 4. Device Queue Head.

### Transfer Descriptors (dQH)

Transfer Descriptors hold information that effectively describe the DMA transfers that need to take place in order to move packets between the system memory and TX/RX Buffers.

The Total Bytes field specifies the number of bytes that the device controller is supposed to transmit or receive in order to consider a transfer completed.

The Status field is written back by the device controller once a transfer is completed. Only bit 7 is currently used, which represents the active status.

The Buffer Pointer (The device controller currently uses only Page 0) field and the Current Offset field are used to determine the memory address where packet data is stored.

The Terminate Transfer (T) bit is set by software if the dTD is the last in the linked list. If T is cleared, the device controller will fetch the next dTD using the information in the Next dTD Pointer field to determine its address.

The Next dTD Pointer field specifies the address of the following dTD in the linked list.

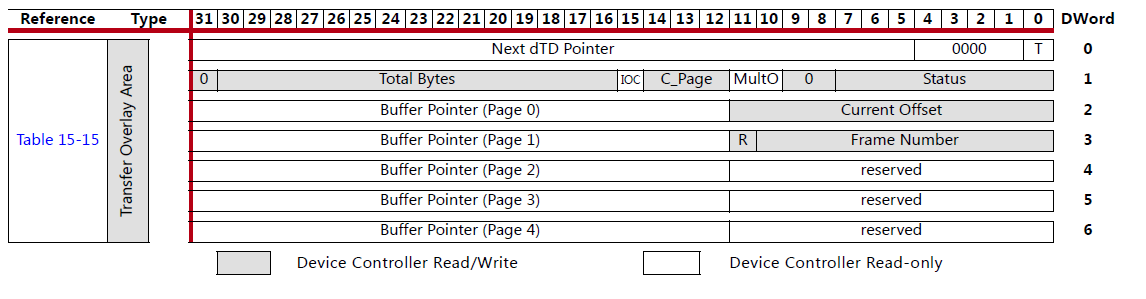
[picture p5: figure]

Figure 5. Device Transfer Descriptor

## Device Frameworks

### Priming

Because of the strict timing requirements on the USB bus, data is loaded in the transmit buffers in advance. This procedure is called priming and it is different between transmit endpoints and receive endpoints.

#### 5.1.1.1 Transmit Endpoints

1. The device controller fetches the queue head (dQH) from main memory based on the address written by software in ENPOINTLISTADDR register.
2. The device controller fetches the transfer descriptor from system memory from the address specified in the Next dTD Pointer field of the previously transferred dQH.
3. The device controller fetches packet data from main memory and fills the transmit buffer based on the address specified in the Buffer Pointer and Current Offset fields of the previously transmitted dTD.
4. The device controller updates its “copy” of the Next dTD Pointer field so that it points to the remaining packet data (if any). When an IN packet will be sent by the host data will be fetched from that address.
5. The device controller will update the ENPTSTAT and ENDPTPRIME registers.

#### 5.1.1.2 Receive Endpoints

1. The device controller fetches the queue head (dQH) from main memory based on the address written by software in ENPOINTLISTADDR register.
2. The device controller fetches the transfer descriptor from main memory from the addres specified in the Next dTD Pointer field of the previously transferred dQH.
3. When an OUT packet will be sent by the host, data from the receive buffer will be transferred by the device controller into main memory at the address specified in the Buffer Pointer and Current Offset fields.
4. The device controller will update the ENPTSTAT and ENDPTPRIME registers

### Setup Packet Framework

Unless the SLOM bit in USBMODE register is set, the device controller copies the setup packet bytes into the corresponding dQH in system memory through a DMA transfer. If the interrupts are enabled and the UI (Bit 0 in USBINTR register) condition is not masked the core will trigger an interrupt.

### IN Packet Framework

This sequence of events is triggered when the device successfully responds with data to an IN tken packet.

1. The device controller checks if there are any bytes left to transmit for the current dTD.
2. If all bytes specified by the dTD have been transmitted, the dTD is copied back in the system memory with its Status field updated. Otherwise, the state machine jumps to step 4.
3. If the Terminate bit is set, the controller considers the transfer specified by the processed dTD completed and takes no further action. If Terminate bit is cleared, the next dTD in the linked list is fetched from main memory from the address specified by the Next dTD Pointer field.
4. If there are bytes left to transmit for the current dTD, the device controller computes the address in the data buffer where the remaining data resides and triggers a new DMA transfer. When the data has been transferred to the TX Buffer, the controller will be ready to respond to a new IN token sent by the host.

# 6 Mouse Emulation

The functionality of the core is demonstrated by emulating a mouse on the Genesys2 board. The pointer can be moved with the push-buttons on the board.

The enumeration process on the device side is carried out by endpoint0. After the speed negotiation is done, the host will request several descriptors from the device. This requests are encoded in setup packets. The sequence of events is as follows:

1. The host sends a Token packet with its PID indicating a SETUP token.
2. The host sends an OUT packet with the 8 bytes that make up the setup information.
3. The device controller will copy the setup packet in main memory, more specifically in the corresponding dQH in the Setup Buffer Bytes fields and triggers an interrupt.
4. The device driver is responsible with preparing the requested response and priming endpoint0.
5. Meanwhile, the device controller will issue NAK handshake packets in response to IN packets received from the host. Once the endpoint is primed, the device controller will issue a DATA1 packet in response to the IN sent by the host.
6. If an ACK handshake token is received from the host, the device controller will set the corresponding bit in ENPTCOMPLETE register.
7. The device controller driver is responsible to check if a zero length packet (the status phase of the control transfer) was received from the host.

This sequence will repeat for all the following control transfers initiated by the host. The descriptors required are: Device Descriptor, Configuration Descriptor, Device Qualifier Descriptor, String Descriptor0, String Descriptor1, String Descriptor2, String Descriptor3, HID Report Descriptor. Once the host gathers all this information will start sending IN tokens on endpoint1. The length and format of the information coded in the HID reports is specified in the HID Report Descriptor.

# 7 Limitations

            1. ULPI: Extended Register Write (EXTW) and Extended Register Read are not verified (not needed for the current application). Packet abort is not supported yet.
            2. HS_Negotiation (Chapter7): Suspend and Resume are not tested. Remote Wakeup not implemented. Full Speed and Low Speed not tested.
            3. Packet_Decoder(Chapter8): Dev_HS_Ping, Dev_Do_BCINTO are not tested. Isochronous transfers are not supported. OUT transactions are not working, need to be fixed. OUT packets are not used with input devices by the HID protocol.
            4. Device Data Structures (Context): IOC is ignored. Interrupts are generated when a dTD is complete regardless of IOC value. Status field of the dTD in not checked by software and is not correctly written back by hardware. MultO is ignored (it should only be used with isochronous transfers which are not supported yet). Mult (used only with isochronous packets) field ignored. ZLT field ignored. Zero Length transfers are dictated by software (dTDs with Total Bytes field set to 0) only.
            5. DMA_Transfer_Manager: Active Status issue. The ZYNQ USB core seems to periodically read dTDs from main memory and, if the software modifies the active bit after the dTD has been copied in the Device Controller memory, the Device Controller will still execute the transfer described by the dTD. This issue was noticed with circular buffers. In the current implementation, if the dTD is inactive, the USB Device controller will stall. This bit is only used to indicate that the Device controller has released a buffer.
            6. Control Registers: Only registers mentioned in section 5 have been tested. Not all ZYNQ USB core registers have been implemented.

# 8 References

The following documents provide additional information on the subjects discussed:

1. Xilinx Inc., UG585: Zynq-7000 AP SoC Technical Reference Manual, v1.10, February 23, 2015.
2. UTMI+ Low Pin Interface (ULPI) Specification, Revision 1.1, October 20th, 2004.
3. Universal Serial Bus Specification Revision 2.0, April 27, 2000

Copyright Digilent, Inc. All rights reserved. Other product and company names mentioned may be trademarks of their respective owners. Page 10 of 11

DOC#: 506-030 Copyright Digilent, Inc. All rights reserved. Other product and company names mentioned may be trademarks of their respective owners. Page 1 of 11

USB Device IP Core User Guide

1300 Henley Court Pullman, WA 99163 509.334.6306 www.digilentinc.com USB Device IP Core User Guide Revised May 18, 2020; Author Tudor Gherman

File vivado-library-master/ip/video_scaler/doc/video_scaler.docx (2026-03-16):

# 1 Introduction

IP quick facts
Supported device families | Zynq®-7000, 7 series
Supported user interfaces | Xilinx®: AXI4-Lite, AXI-Stream

Provided with core
Design files | VHDL
Simulation model | VHDL Behavioral
Constraints file | XDC
Software driver | standalone

Tested design flows
Design entry | Vivado™ HLS 2018.2
Synthesis | Vivado Synthesis 2018.2

This user guide describes the Digilent Video Scaler Intellectual Property. It takes video frames of arbitrary resolution over a slave AXI-Stream interface, resizes them to an arbitrary output resolution and outputs on a master AXI-Stream interface. It has an AXI4-Lite interface for control.

# 2 Features

- One pixel per beat
- 24-bit color depth
- RGB format
- Xilinx interfaces used: AXI4-Lite, AXI-Stream Port Descriptions

# 3 Designing with the core

## Constraints

## Customization

# 4 Register map

Offset | Register Name | Description
0x00 | Control signals | bit 0 - ap_start (Read/Write/COH) bit 1 - ap_done (Read/COR) bit 2 - ap_idle (Read) bit 3 - ap_ready (Read) bit 7 - auto_restart (Read/Write) others - reserved
0x04 | Global Interrupt Enable Register | bit 0 - Global Interrupt Enable (Read/Write)
0x08 | IP Interrupt Enable Register (Read/Write) | bit 0 - Channel 0 (ap_done) bit 1 - Channel 1 (ap_ready)
0x0C | IP Interrupt Status Register (Read/TOW) | bit 0 - Channel 0 (ap_done) bit 1 - Channel 1 (ap_ready)
0x10 | Data signal of in_width | bit 31~0 - in_width[31:0] (Read/Write)
0x18 | Data signal of in_height | bit 31~0 - in_height[31:0] (Read/Write)
0x20 | Data signal of out_width | bit 31~0 - out_width[31:0] (Read/Write)
0x28 | Data signal of out_height | bit 31~0 - out_height[31:0] (Read/Write)

// (SC = Self Clear, COR = Clear on Read, TOW = Toggle on Write, COH = Clear on Handshake)

# 5 Debugging

Opening the IP in HLS is possible by executing the following command in the Vivado HLS Command Prompt:

cd <path_to_IP>/hls_src

vivado_hls -f script.tcl

# 6 References

Copyright Digilent, Inc. All rights reserved. Other product and company names mentioned may be trademarks of their respective owners. Page 2 of 2

DOC#: 516-000 Copyright Digilent, Inc. All rights reserved. Other product and company names mentioned may be trademarks of their respective owners. Page 1 of 2

Video Scaler 1.0 IP Core User Guide

1300 Henley Court Pullman, WA 99163 509.334.6306 www.digilentinc.com Video Scaler 1.0 IP Core User Guide Revised January 28, 2019; Author Elod Gyorgy

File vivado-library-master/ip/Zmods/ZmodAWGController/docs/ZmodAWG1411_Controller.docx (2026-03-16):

# 1 Introduction

IP quick facts
Supported device families | Zynq®-7000, 7 series
Supported user interfaces | Custom, AXI Stream

Provided with core
Design files | VHDL
Simulation model | Yes for AD9717 SPI interface; No for he IP itself (it can be simulated using the design fies)
Constraints file | XDC
Software driver | N/A

Tested design flows
Design entry | Vivado™ Design Suite 2019.1
Synthesis | Vivado Synthesis 2019.1

This user guide describes the Digilent Zmod AWG 1411 Controller Intellectual Property (IP). This IP interfaces directly with the Zmod AWG 1411 initializing the hardware and encoding the samples received over the Input Data Stream interface (AXI Stream) on a single double data rate (DDR) channel as required by the AD9717 digital to analog converter (DAC) featured by the Zmod AWG 1411. The Zmod AWG 1411 Low Level Controller is intended to be used as a stand-alone IP in projects that do not require processor interaction (standalone mode) or it can be used in conjunction with higher level IPs that may provide connectivity with the processing system.

# 2 Features

- Initializes the hardware on the Zmod AWG 1411.
- Formats the data received on the Input Data Stream interface (AXI Stream slave) according to the Zmod AWG 1411 requirements.
- Provides the possibility of overwriting the initial DAC configuration by providing an optional upper level interface that allows indirect access to the DAC’s SPI interface.
- Performs offset and gain calibration based on coefficients specified by the user/upper level IPs.

# 3 Performance

This IP is designed to allow a variable sample rate for the Zmod AWG 1411, the maximum sample rate being limited by the capabilities of the AD9717 DAC (125MSPS) [1] and those of the FPGA [2]. The two clock signals required by the AD9717 need to be configured in the top level design and are only forwarded by this IP on the Zmod’s external pins (one clock signal used to qualify the data at the input of the AD9717 device and one used as sample clock).

The data path of this IP is responsible with decoding the Input Data Stream interface, applying the calibration coefficients to the input samples and encoding the outputs of the calibration blocks in the format required by the AD9717 DAC. This process allows achieving the accuracy specified for the Zmod AWG 1411 (Zmod AWG Reference Manual (https://reference.digilentinc.com/reference/zmod/zmoddac/reference-manual)).

# 4 Overview

Figure 1. Zmod AWG 1411 Controller block diagram.

The structure of the IP is presented in Figure 1. The main functionalities are divided as DAC input clock generation, data formatting and calibration (data path) and Zmod AWG 1411 configuration (two items related with configuration functionalities will be detailed separately: the configuration state machine and the SPI controller).

## Clocking

This IP requires 3 input clocks which divide it in 3 distinct clock domains as shown in Figure 1:

            1. The system clock domain (SysClk100) clocks the DAC configuration module including the SPI controller. The frequency of this clock is expected to be 100MHz. All signals synchronous with SysClk100 have the prefix “s”.
            2. The sample clock (DAC_InIO_Clk) clocks the data path related logic including the calibration module. It is important to note that, although this IP processes input and output samples in this clock domain, the DAC will be forwarded a phase shifted version of this clock so that timing on the DAC’s data interface can be achieved. All signals synchronous with DAC_InIO_Clk have the prefix “c”.
            3. The DAC clock (DAC_Clk) should have the same frequency but a 90° phase shift with respect to DAC_InIO_Clk. DAC_Clk is used to generate the DCLKIO (labeled ZmodDAC_ClkIO) and DCLKIN (labeled ZmodDAC_ClkIn) signals for the AD9717 DAC. All signals synchronous with DAC_Clk have the prefix “d”. Note that the external data port of the AD9717 data interface is named dZmodDAC_Data, even though dZmodDAC_Data is generated in the DAC_InIO_Clk domain. This choice of naming was made to emphasize that, at the DAC’s input, the data signals are sampled on the ZmodDAC_ClkIO clock.

This IP does not constrain the clocks it requires as inputs. The exception is out-of-context synthesis, where the ConstrZmodDAC1411_ooc.xdc contains the necessary constraints. However, this file is not used in top-level synthesis. Therefore, clocks need to be constrained in the top-level design either manually or by relying on the auto-derived constraints, if using clock modifying blocks. For more information see [3].

## Reset

This IP has a single asynchronous reset input with negative polarity (aRst_n) which resets the logic in all 3 clock domains. To assure that recovery/removal time of sequential logic is respected, the reset input is distributed to the different clock domains throughout the IP by ResetBridge modules. The ResetBridge modules are responsible with converting the asynchronous reset input in reset signals with synchronous de-assertion (RSD) for each clock domain.

The input reset (aRst_n) must be asserted for at least 2*Tslowest, where Tslowest represents the period of the slowest clock input of the IP.

## Data Path

The data path consists of 3 stages: Input Data Stream interface decode, calibration and output data encoding. Each of these stages is described separately below.

### Input Data Stream Interface Decode

Data is sent to the Zmod AWG 1411 Low Level Controller over an AXI Stream interface (named InputDataStram), the Zmod AWG 1411 Low Level Controller being a slave on this interface. Since the samples received are processed in real time, the TREADY signal of the Input Data Stream interface is always asserted. The TDATA signal is encoded as follows:

31 18 | 17 16 | 15 2 | 1 0
Channel 1 DAC code (14 bit) | 00 | Channel 2 DAC code (14 bit) | 00

Channel 1 and Channel 2 input codes are further passed to the appropriate calibration modules. If the TVALID signal is de-asserted, the inputs of the calibration modules hold the value of the last valid code.

### Calibration (GainOffsetCalib.vhd)

To generate a particular voltage value at the output of the Zmod AWG 1411, the user application sends a signed 14 bit integer to the DAC. This value needs to consider the gain and offset errors in order to obtain the expected accuracy for the output, thus a calibration process needs to be applied. The DAC code is computed as:

, N_(calib) =((V_(out) -CA))/((1+CG)*Range)*2^13 #(1)

were:

- Ncalib = the 14 bit, 2's complement integer sent to the DAC that accounts for gain and offset errors.
- Vout= the desired value of the output voltage.
- CA = factory calibration raw additive constant (for the appropriate channel and gain).
- CG = factory calibration raw gain constant (for the appropriate channel and gain).
- Range = the theoretical range of the DAC’s channel output stage
  - 1.33 (for low gain: ±1.25 V) or
  - 5.32 (for high gain: ±5 V)

The raw calibration additive and gain constants are computed and saved in the Zmod’s calibration memory at manufacturing time, as described in the Zmod AWG Reference Manual (https://reference.digilentinc.com/reference/zmod/zmoddac/reference-manual). Using a fractional representation for the DAC code N, Eq (1) can be rearranged as:

, V_(out) =N_(calib_(fract)) *(1+CG)*Range+CA #(2)

The purpose of the calibration block is to provide an ideal representation of the DAC to the upper levels. By adding the calibration block, the user may send a code as for an ideal DAC having the output range equal to Rangeideal (1.25 V for the low gain option and 5 V for the high gain option) and the calibration block will apply the offset and gain coefficients so that:

, V_(out) =N_(raw_(fract)) *Range_(ideal) #(3)

From Eq (2) and Eq (3) one can obtain:

N_(calib_(fract)) *(1+CG)*Range+CA=N_(raw_(fract)) *Range_(ideal) =>

, N_(calib_(fract)) =N_(raw_(fract)) *CoefMult-CoefAdd#(4)

where:

, CoefMult=(Range_(ideal))/((1+CG)*Range)#(5)

, CoefAdd=(CA)/((1+CG)*Range)#(6)

CoefMult and CoefAdd are fractional numbers computed for each channel and each gain option. CoefMult and CoefAdd are further scaled so that they can be passed as integer numbers to the IP:

, CoefMult_(scaled) =CoefMult*2^16 #(7)

, CoefAdd_(scaled) =CoefAdd*2^17 #(8)

The numerical representation of the operands of the calibration process is illustrated in Figure 2. The scaled version of CoefMult and CoefAdd are named “processed calibration coefficients” and these are the constants required by the GainOffsetCalib module. One can note (Figure 2) that the GainOffsetCalib converts the processed calibration coefficients back to their fractional representation.

The multiplicative and additive coefficients are passed by the upper layer IP Core if the Zmod AWG 1411 Controller is used in a processor system (the external calibration interface is enabled) or they can be passed as IP core parameters otherwise. The user can obtain the calibration coefficients by booting the Eclypse board with the Linux image provided at https://github.com/Digilent/Eclypse-Z7/releases and run the "decutil enum" command in the command line. The Zmod AWG 1411 has to be plugged in one of the Eclypse’s board SYZYGY ports. The Digilent Eclypse Utility (decutil) provides a command line interface for discovering information about the features and configuration of an Eclypse platform board. Decutil reports the factory raw calibration parameters and processed calibration parameters as shown in Figure 3.

Figure 2: Calibration process

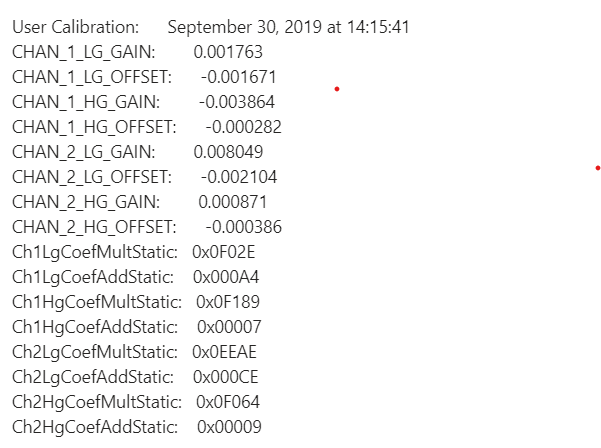
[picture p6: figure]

Processed calibration

coefficients

Raw calibration

coefficients

Figure 3: Obtaining calibration prameters from decutil

The parameters and ports of the calibration module are listed below:

Table 1. Calibration module parameter descriptions.

Signal Name | Description
kWidth | ADC/DAC resolution.
kExtCalibEn | Enables the external calibration interface. Set to “true” when the IP core is expected to be interfaced with the processing system through a high level IP. Set to “false” when the core operates in stand alone mode.
kInvert | When asserted, kInvert determines the sign inversion of the data samples received. Used to compensate the physical inversion of some of the channels on the PCB at the ADC/DAC input/output on the Zmod.
kLgMultCoefStatic[17:0] | Low gain multiplicative calibration coefficient. If the kExtCalibEn parameter is set to “false”, the calibration block will expect the value of the multiplicative coefficient to be passed by this parameter. If the value of kExtCalibEn parameter is “true”, this parameter is ignored, and the high level IP is expected to update the corresponding external port.
kLgAddCoefStatic[17:0] | Low gain additive calibration coefficient. If the kExtCalibEn parameter is set to “false”, the calibration block will expect the value of the additive coefficient to be passed by this parameter. If the value of kExtCalibEn parameter is “true”, this parameter is ignored, and the high level IP is expected to update the corresponding external port.
kHgMultCoefStatic[17:0] | High gain multiplicative calibration coefficient. If the kExtCalibEn parameter is set to “false”, the calibration block will expect the value of the multiplicative coefficient to be passed by this parameter. If the value of kExtCalibEn parameter is “true”, this parameter is ignored, and the high level IP is expected to update the corresponding external port.
kHgAddCoefStatic[17:0] | High gain additive calibration coefficient. If the kExtCalibEn parameter is set to “false”, the calibration block will expect the value of the additive coefficient to be passed by this parameter. If the value of kExtCalibEn parameter is “true”, this parameter is ignored, and the high level IP is expected to update the corresponding external port.

Table 2. Calibration module port description

Signal Name | Interface | Signal Type | Init State | Description
SamplingClk | - | I | N/A | Calibration module clock input.
acRst_n | - | I | N/A | Active low reset (can be asynchronously asserted but synchronously de-asserted in the sampling clock domain).
cTestMode | - | I | N/A | cTestMode is used to bypass the calibration block. When asserted, raw samples are sent to the DAC.
cExtLgMultCoef[17:0] | - | I | N/A | Low gain multiplicative coefficient external port. This port is enabled by setting the ExtCalibEn parameter to “true”.
cExtLgAddCoef[17:0] | - | I | N/A | Low gain additive coefficient external port. This port is enabled by setting the ExtCalibEn parameter to “true”.
cExtHgMultCoef[17:0] | - | I | N/A | High gain multiplicative coefficient external port. This port is enabled by setting the ExtCalibEn parameter to “true”.
cExtHgAddCoef[17:0] | - | I | N/A | High gain additive coefficient external port. This port is enabled by setting the ExtCalibEn parameter to “true”.
cGainState | - | I | N/A | Corresponding channel selected gain option. The ADC /DAC calibration module needs to be aware of the gain setting to apply the appropriate calibration coefficients, which are different between the low gain option and the high gain option. The relay gain state is provided by the Relay Configuration module. • 1 = High Gain. • 0 = Low Gain.
cDataRaw[Width-1 : 0] | - | I | N/A | Input raw samples provided by the Data Path module.
cDataInValid | - | I | N/A | Data valid indicator provided by the Data Path module.
cCalibDataOut[15 : 0] | - | O | N/A | Calibrated data output. Regardless of the ADC/DAC resolution, the output of the calibration process is represented on 16 bits.
cDataCalibValid | - | O | N/A | Delayed version of cDataInValid. The same latency obtained for the calibration process (3 sampling clock cycles) is added to the input valid indicator to obtain cDataCalibValid.

### Output Data Encoding

Each of the output bits of the calibration stage is further connected to an ODDR primitive which formats the output data on a DDR interface according to the AD9717 requirements. The output of the Channel 1’s calibration module is connected to the D1 input of the ODDR primitives (ODDR_D1), while the output of Channel 2’s calibration module is connected to the D2 input (ODDR_D2) [4]. The output data encoding process is illustrated in Figure 4.

Figure 4: DAC data formatting

## Gain Select

The IP core provides the choice of selecting the Zmod AWG 1411 gain options statically or dynamically. For static configuration, the kExtScaleConfigEn needs to be set as “false” and the gain configuration parameters (kCh1ScaleStatic, kCh2ScaleStatic) need to be configured in the IP core GUI. For dynamic gain control, the kExtScaleConfigEn needs to be set as “true” and the external gain control ports (sExtCh1Scale, sExtCh2Scale) will become available.

The gain configuration signals also need to be passed to the calibration module (GainOffsetCalib.vhd) so that the correct calibration coefficients can be applied. For this, the configuration signals need to cross clock domains, from the SysClk100 domain to the DAC_InIO_Clk domain where the calibration module operates. Due to the latency associated with the clock domain crossing, the register stages in the data path and the register stages in the calibration module the output data (dZmodDAC_Data) may have incorrect values for kSysClkPeriod + 6*kDacClkPeriod, where kSysClkPeriod represents the period of the SysClk100 clock signal and kDacClkPeriod represents the period of DAC_InIO_Clk clock signal.

## DAC Configuration (ConfigDAC.vhd)

The DAC Configuration block sends a predefined list of SPI commands to the Zmods DAC 1411, performing the DAC initialization, and manages the SPI Indirect Access Port (IAP). The ports and parameters of the DAC configuration block, which is implemented as a distinct VHDL module are listed below:

Table 3. DAC Configuration parameter description

Parameter Name | Description
kDataWidth | The number of data bits for the data phase of the transaction: only 8 data bits currently supported, parameter provided for future development.
kCommandWidth | The number of bits of the command phase of the SPI transaction.

Table 4. DAC Configuration port description

Signal Name | Interface | Signal Type | Init State | Description
SysClk100 | - | I | N/A | 100MHz input clock signal.
asRst_n | - | I | N/A | Active low reset (can be asynchronously asserted but synchronously de-asserted).
sZmodDAC_SCLK | SPI | O | N/A | Output SPI clock. Signal managed by the SPI controller. More details in section 4.6.
sZmodDAC_SDIO | SPI | IO | N/A | 2 Wire SPI interface SDIO signal. Signal managed by the SPI controller. More details in section 4.6.
sZmodDAC_CS | SPI | O | N/A | 2 Wire SPI interface CS signal. Signal managed by the SPI controller. More details in section 4.6.
sInitDoneDAC | - | O | N/A | Flag indicating when the Zmod’s DAC 1411 initialization is complete.
sConfigError | - | O | N/A | This flag is asserted if the DAC initialization fails. An IP reset is required to clear this flag.
sCmdTxAxisTdata[31:0] | SPI IAP | I | N/A | IAP command TX interface (AXI Stream) data port.
sCmdTxAxisTvalid | SPI IAP | I | N/A | IAP command TX interface (AXI Stream) valid signal.
sCmdTxAxisTready | SPI IAP | O | N/A | IAP command TX interface (AXI Stream) ready signal.
sCmdRxAxisTdata[31:0] | SPI IAP | O | N/A | IAP command RX interface (AXI Stream) data port.
sCmdRxAxisTvalid | SPI IAP | O | N/A | IAP command RX interface (AXI Stream) valid signal.
sCmdRxAxisTready | SPI IAP | I | N/A | IAP command RX interface (AXI Stream) ready signal.

Once the initialization is complete, the state machine of the DAC configuration block enters the idle state where it monitors if there is any valid data on the upper level SPI command interface named the SPI Indirect Access port (IAP). After executing the requested SPI transfers, the state machine passes the received SPI data (for read commands) and returns to the idle state. The SPI IAP is optional, and it can be enabled by setting the kExtCmdInterfaceEn to “true”. It is designed to interface with 2 AXI StreamFIFOs, one that stores commands to be transmitted (command queue TX FIFO) and one to store the received data (command RX FIFO). Thus, the IAP consists of two AXI Stream interfaces: the IAP command TX interface and the IAP RX command interface. Each element of the command queue should be represented on 32 bits, having the following format:

31 24 | 23 | 22 21 | 20 13 | 12 8 | 7 0
- | Read/Write | Width | | Address | Data

Bits | Field Name | Description
23 | Read/Write | Write this bit to 1 for a read command and to 0 for a write command
22-21 | Width | Only 1 byte SPI transfers are supported. This field should be always 0h.
12-8 | Address | DAC SPI register address
7-0 | Data | Data byte to be sent to the AD9717. Ignored for read operations.

The DAC Configuration state machine, when in the idle state, monitors the valid signal of the IAP command TX interface (sCmdTxAxisTvalid) and, if asserted and if the SPI controller can process a new command (not busy), the ready signal of the IAP command TX interface is asserted for one SysClk100 clock cycle. Write commands only consist of a single transaction on the IAP command TX interface. For read commands, after passing the register read request to the SPI controller and the request successfully completes, the DAC Configuration state machine asserts the valid signal of the IAP command RX interface (sCmdRxAxisTvalid) and places the register read data on the data port of the interface (sCmdRxAxisTdata). The DAC Configuration state machine waits for the upper layer IP to assert the ready signal o the IAP command interface (sCmdRxAxisTready) before it transitions to the idle state.

The initialization configuration command sequence is listed below. After configuring each register, the register data is read back and checked against the expected value in order to determine any SPI transaction error.

1. SPI Control register: Set software reset (Address: 00h; Data: 20h)
2. SPI Control register: Release software reset (Address: 00h; Data: 00h)
3. Data Control Register: Configuration selected: 2’s complement, IDATA latched on DCLKIO rising edge, I first of pair on data input pads, data clock input enable, data clock output disable (Address: 02h; Data: B4h)
4. CLKMODE Register: Clear the reacquire bit (Address: 14h; Data: 00h)
5. CLKMODE Register: Set (toggle) the require bit (Address: 14h; Data: 08h)
6. CLKMODE Register: Clear the reacquire bit (Address: 14h; Data: 00h)
7. Memory R/W Register: Reset UNCALI and UNCALQ bits are reset (Address: 12h; Data: 00h)
8. Cal Control Register: Set up calibration clock to SysClk/64 (Address: 0Eh; Data: 02h)
9. Cal Control Register: Enable calibration clock (Address: 0Eh; Data: 0Ah)
10. Cal Control Register: Select the DAC to self-calibrate (Address: 0Eh; Data: 3Ah)
11. Memory R/W Register: Start self-calibration (Address: 12h; Data: 10h)
12. Cal Control Register: Check if self-calibration has completed by reading CALSTATI and CALSTATQ bits (Address: 0Fh; Data: -)
13. Memory R/W Register: Clear register (Address: 12h; Data: 00h)
14. Cal Control Register: Disable calibration clock (Address: 0Eh; Data: 00h)

## SPI Controller (ADI_SPI.vhd)

The SPI controller is designed to carry out basic register access over the Analog Devices 2 wire SPI interface. The controller’s parameters and ports are listed below:

Table 5. SPI controller parameter description

Parameter Name | Description
kSysClkDiv | The sSPI_Clk signal is obtained by dividing SysClk100 to 2kSysClkDiv.
kDataWidth | The number of data bits for the data phase of the transaction: only 8 data bits currently supported, parameter provided for future development.
kCommandWidth | The number of bits of the command phase of the SPI transaction.

Table 6. SPI controller port description

Signal Name | Interface | Signal Type | Init State | Description
SysClk100 | - | I | N/A | 100MHz input clock signal.
asRst_n | - | I | N/A | Active low reset (can be asynchronously asserted but synchronously de-asserted).
sSPI_Clk | SPI | O | N/A | Output SPI clock [1] divided from SysClk100. Connected directly to the corresponding Zmod port.
sSDIO | SPI | IO | N/A | 2 Wire SPI interface SDIO signal [1]. Connected directly to the corresponding Zmod port.
sCS | SPI | O | N/A | 2 Wire SPI interface CS signal [1]. Connected directly to the corresponding Zmod port.
sApStart | - | I | N/A | A pulse on this input initiates the transfers. When asserted, the inputs of the upper layer interface are also registered.
sRdData[kDataWidth-1 : 0] | - | O | N/A | SPI register read received data
sWrData[kDataWidth-1 : 0] | - | I | N/A | SPI register write data.
sAddr[kCommandWidth - 4:0] | - | I | N/A | SPI instruction phase address.
sWidth[1:0] | - | I | N/A | SPI instruction phase word length. The only value currently supported is 0 (1 data byte transferred).
sRdWr | - | I | N/A | Encodes the requested transaction type: ‘1’ - read transaction. ‘0’ – write transaction.
sDone | - | O | N/A | Indicates that the operation requested has completed and that the data placed on the sRdData port is valid.
sBusy | - | O | N/A | Indicates when a new command can be processed. sApStart is ignored while this signal is asserted.

A SPI transaction is triggered by generating a pulse on the sApStart input. When the pulse is detected, the inputs of the upper layer interface are also registered. The sRdWr signal encodes the type of the transaction (read/write). The SPI controller further constructs the command word and the data word based on the module’s inputs and formats them on the SPI bus as requested by the Analog Device’s specifications [1]. For read operations, the received data is outputted on the sRdData port and can be read by the upper layer module when the sDone signal pulses high. When the SPI controller returns to the idle state and is ready to process new commands, the sBusy output signal is de-asserted. The sApStart signal is ignored while sBusy is asserted. The width of the command word is configurable through the kCommandWidth generic. The frequency of the SPI output clock is obtained by dividing the controller’s input clock frequency with by a factor of 2kSysClkDiv (kSysClkDiv is also a generic). Only single byte data transfers are currently supported. More details about the DAC’s SPI interface can be found in [1].

# 5 IP Top-Level Parameter Description

Table 7. IP core parameter descriptions.

Signal Name | Description
kDAC_Width | DAC resolution (number of bits). It is set to 14 and it is not visible in the customization GUI.
kExtScaleConfigEn | Enables the external gain configuration port. Set to “true” when dynamic configuration is required. Set to “false” when static configuration is sufficient.
kExtCalibEn | Enables the external calibration interface. Set to “true” when the IP core is expected to be interfaced with the processing system through a high level IP. Set to “false” when the core operates in stand alone mode.
kExtCmdInterfaceEn | Enables the upper layer IP SPI configuration interface. Set to “true” when the IP core is expected to be interfaced with the processing system through a high level IP. This will enable the processor to access the Zmod AWG 1411 SPI interface. Set to “false” when initial configuration described in Section 4.5 is sufficient.
kCh1ScaleStatic | Channel1 gain select static configuration parameter. If the kExtRelayConfigEn parameter is set to “false”, the Zmod’s gain will be configured according to this parameter’s value at initialization time. If the value of kExtRelayConfigEn parameter is “true”, this parameter is ignored. • 1 = High Gain. • 0 = Low Gain.
kCh2ScaleStatic | Channel2 gain select static configuration parameter. If the kExtRelayConfigEn parameter is set to “false”, the Zmod’s gain will be configured according to this parameter’s value at initialization time. If the value of kExtRelayConfigEn parameter is “true”, this parameter is ignored. • 1 = High Gain. • 0 = Low Gain.
kCh1LgMultCoefStatic[17:0] | Channel1 low gain multiplicative calibration coefficient. If the kExtCalibEn parameter is set to “false”, the calibration block will expect the value of the multiplicative coefficient to be passed by this parameter. If the value of kExtCalibEn parameter is “true”, this parameter is ignored, and the high level IP is expected to update the corresponding external port.
kCh1LgAddCoefStatic[17:0] | Channel1 low gain additive calibration coefficient. If the kExtCalibEn parameter is set to “false”, the calibration block will expect the value of the additive coefficient to be passed by this parameter. If the value of kExtCalibEn parameter is “true”, this parameter is ignored, and the high level IP is expected to update the corresponding external port.
kCh1HgMultCoefStatic[17:0] | Channel1 high gain multiplicative calibration coefficient. If the kExtCalibEn parameter is set to “false”, the calibration block will expect the value of the multiplicative coefficient to be passed by this parameter. If the value of kExtCalibEn parameter is “true”, this parameter is ignored, and the high level IP is expected to update the corresponding external port.
kCh1HgAddCoefStatic[17:0] | Channel1 high gain additive calibration coefficient. If the kExtCalibEn parameter is set to “false”, the calibration block will expect the value of the additive coefficient to be passed by this parameter. If the value of kExtCalibEn parameter is “true”, this parameter is ignored, and the high level IP is expected to update the corresponding external port.
kCh2LgMultCoefStatic[17:0] | Channel2 low gain multiplicative calibration coefficient. If the kExtCalibEn parameter is set to “false”, the calibration block will expect the value of the multiplicative coefficient to be passed by this parameter. If the value of kExtCalibEn parameter is “true”, this parameter is ignored, and the high level IP is expected to update the corresponding external port.
kCh2LgAddCoefStatic[17:0] | Channel2 low gain additive calibration coefficient. If the kExtCalibEn parameter is set to “false”, the calibration block will expect the value of the additive coefficient to be passed by this parameter. If the value of kExtCalibEn parameter is “true”, this parameter is ignored, and the high level IP is expected to update the corresponding external port.
kCh2HgMultCoefStatic[17:0] | Channel2 high gain multiplicative calibration coefficient. If the kExtCalibEn parameter is set to “false”, the calibration block will expect the value of the multiplicative coefficient to be passed by this parameter. If the value of kExtCalibEn parameter is “true”, this parameter is ignored, and the high level IP is expected to update the corresponding external port.
kCh2HgAddCoefStatic[17:0] | Channel2 high gain additive calibration coefficient. If the kExtCalibEn parameter is set to “false”, the calibration block will expect the value of the additive coefficient to be passed by this parameter. If the value of kExtCalibEn parameter is “true”, this parameter is ignored, and the high level IP is expected to update the corresponding external port.

# 6 IP Top-Level Port Description

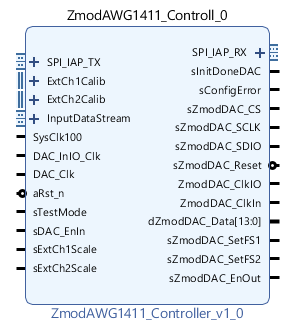
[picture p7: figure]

Figure 5: Zmod AWG 1411 Controller IP.

Table 8. IP core port description

Signal Name | Interface | Signal Type | Init State | Description
SysClk100 | - | I | N/A | 100MHz input clock signal.
DAC_InIO_Clk | - | I | N/A | Data path clock input.
DAC_Clk | - | I | N/A | Input clock used to generate the ZmodDAC_ClkIO and ZmodDAC_ClkIn output clock signals for the AD9717 DAC. DAC_Clk should have the same frequency but a 90° phase shift with respect to DAC_InIO_Clk.
aRst_n | - | I | N/A | Asynchronous reset of negative polarity which resets the logic in all four clock domains. Must must be asserted for at least 2*Tslowest.
sInitDoneDAC | - | O | N/A | Flag indicating when the Zmod’s DAC 1411 initialization is complete.
sConfigError | - | O | N/A | This flag is asserted if the DAC initialization fails. An IP reset is required to clear this flag.
cDataAxisTdata[31:0] | Input Data Stream | I | N/A | (Slave) AXI Stream Data interface TDATA port. Channel1 and Channel2 data are concatenated as follows: Channel1 -> cDataAxisTdata[31:18]. Channel2 -> cDataAxisTdata[15:2].
cDataAxisTvalid | Input Data Stream | I | N/A | (Slave) AXI Stream Data interface TVALID signal.
cDataAxisTready | Input Data Stream | O | N/A | (Slave) AXI Stream Data interface TREADY signal.
cExtCh1LgMultCoef[17:0] | ExtCh1Calib | I | N/A | Channel1 low gain multiplicative coefficient external port. This port is enabled by setting the kExtCalibEn parameter to “true”.
cExtCh1LgAddCoef[17:0] | ExtCh1Calib | I | N/A | Channel1 low gain additive coefficient external port. This port is enabled by setting the kExtCalibEn parameter to “true”.
cExtCh1HgMultCoef[17:0] | ExtCh1Calib | I | N/A | Channel1 high gain multiplicative coefficient external port. This port is enabled by setting the kExtCalibEn parameter to “true”.
cExtCh1HgAddCoef[17:0] | ExtCh1Calib | I | N/A | Channel1 high gain additive coefficient external port. This port is enabled by setting the kExtCalibEn parameter to “true”.
cExtCh2LgMultCoef[17:0] | ExtCh2Calib | I | N/A | Channel2 low gain multiplicative coefficient external port. This port is enabled by setting the kExtCalibEn parameter to “true”.
cExtCh2LgAddCoef[17:0] | ExtCh2Calib | I | N/A | Channel2 low gain additive coefficient external port. This port is enabled by setting the kExtCalibEn parameter to “true”.
cExtCh2HgMultCoef[17:0] | ExtCh2Calib | I | N/A | Channel2 high gain multiplicative coefficient external port. This port is enabled by setting the kExtCalibEn parameter to “true”.
cExtCh2HgAddCoef[17:0] | ExtCh2Calib | I | N/A | Channel2 high gain additive coefficient external port. This port is enabled by setting the kExtCalibEn parameter to “true”.
sDAC_EnIn | - | I | N/A | Zmod AWG 1411 output relay control. When set to ‘1’, the Zmod’s analog outputs are enabled. When set to ‘0’, the Zmod’s analog outputs are in high impedance state.
sExtCh1Scale | - | I | N/A | Channel1 gain select external port. This port is enabled by setting the kExtScaleConfigEn parameter to “true”. • 1 = High Gain. • 0 = Low Gain.
sExtCh2Scale | - | I | N/A | Channel2 gain select external port. This port is enabled by setting the kExtScaleConfigEn parameter to “true”. • 1 = High Gain. • 0 = Low Gain.
sTestMode | - | I | N/A | sTestMode is used to bypass the calibration block. When asserted, raw samples are sent to the DAC.
sCmdTxAxisTdata[31:0] | SPI IAP | I | N/A | IAP command TX interface (Slave AXI Stream) data port. For more information see section 4.5.
sCmdTxAxisTvalid | SPI IAP | I | N/A | IAP command TX interface (Slave AXI Stream) valid signal. For more information see section 4.5.
sCmdTxAxisTready | SPI IAP | O | N/A | IAP command TX interface (Slave AXI Stream) ready signal. For more information see section 4.5.
sCmdRxAxisTdata[31:0] | SPI IAP | O | N/A | IAP command RX interface (Master AXI Stream) data port. For more information see section 4.5.
sCmdRxAxisTvalid | SPI IAP | O | N/A | IAP command RX interface (Master AXI Stream) valid signal. For more information see section 4.5.
sCmdRxAxisTready | SPI IAP | I | N/A | IAP command RX interface (Master AXI Stream) ready signal. For more information see section 4.5.
sZmodDAC_ClkIO | Zmod | O | N/A | Should be connected to the AD9717 DCLKIO input [1].
sZmodDAC_ClkIn | Zmod | O | N/A | Should be connected to the AD9717 CLKIN input [1].
sZmodDAC_Data[13:0] | Zmod | O | N/A | Should be connected to the AD9717 DB[13:0] input [1].
sZmodDAC_Reset | Zmod | O | N/A | Should be connected to the AD9717 RESET/PINMD input [1].
sZmodDAC_SDIO | Zmod | IO | N/A | SPI SDIO signal [1].
sZmodDAC_CS | Zmod | O | N/A | SPI CS signal [1].
sZmodDAC_Sclk | Zmod | O | N/A | SPI output clock.
sZmodDAC_SetFS1 | Zmod | O | N/A | This signal controls the Zmod AWG 1411 gain select analog switch for channel1.
sZmodDAC_SetFS2 | Zmod | O | N/A | This signal controls the Zmod AWG 1411 gain select analog switch for channel2.
sZmodDAC_EnOut | Zmod | O | N/A | This signal controls the Zmod AWG 1411 output enable relay.

# 7 IP Core customization

The IP through its customizable parameters (kExtScaleConfigEn, kExtCalibEn, kExtCmdInterfaceEn) enables the user to opt for a more basic design, with minimal external ports or a more configurable but also more complex design with several ports that enable dynamic configuration of several hardware features. When the Zmod AWG 1411 Low Level Controller is controlled by a higher level IP, the hardware configuration features are expected to be controlled by the upper layers (processing system), so all interfaces should be enabled and connected to the upper layer IP Core.

# 8 References

The following documents provide additional information on the subjects discussed:

1. Analog Devices, AD9717 Datasheet, Rev B.
2. Xilinx Inc., UG472: 7 Series FPGAs Clocking Resources, v1.6, October 2, 2012.
3. Xilinx Inc., UG903: Using Constraints, v2014.3, October 31, 2014.
4. Xilinx Inc., UG471: 7 Series FPGAs SelectIO Resources, v1.4, May 13, 2014.

Copyright Digilent, Inc. All rights reserved. Other product and company names mentioned may be trademarks of their respective owners. Page 5 of 5

DOC#: 516-001 Copyright Digilent, Inc. All rights reserved. Other product and company names mentioned may be trademarks of their respective owners. Page 1 of 5

Zmod AWG Low Level Controller 1.0 IP Core User Guide

1300 Henley Court Pullman, WA 99163 509.334.6306 www.digilentinc.com Zmod AWG 1411 Controller IP Core User Guide Revised September 24, 2021; Author Tudor Gherman

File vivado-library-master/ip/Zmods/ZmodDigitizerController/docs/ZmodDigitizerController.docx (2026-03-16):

# 1 Introduction

IP quick facts
Supported device families | Zynq®-7000, 7 series
Supported user interfaces | Custom, AXI Stream

Provided with core
Design files | VHDL
Simulation model | Yes for AD96xx SPI interface; No for the IP itself (it can be simulated using the design files)
Constraints file | XDC
Software driver | N/A

Tested design flows
Design entry | Vivado Design Suite - ML Editions 2021.1
Synthesis | Vivado Synthesis 2021.1
Implementation | Vivado Implementation 2021.1

This user guide describes the Digilent Zmod Digitizer Controller Intellectual Property. This IP interfaces directly with the Zmod Digitizer 1430 – 125 writing an initial configuration to the analog to digital converter (ADC) featured by these modules and one of the selected frequency configurations of the Clock Generator, demultiplexing the data received over the ADC’s parallel interface and forwarding it to the user logic. The Zmod Digitizer Controller is intended to be used as a stand-alone IP (the stand alone mode) in projects that do not require processor interaction or it can be used in conjunction with higher level IPs that may provide connectivity with the processing system.

# 2 Features

- Initializes the hardware on the Zmod Digitizer 1430 – 125.
- Demultiplexes the double data rate (DDR) parallel interface outputted by the Zmod and exports two single data rate (SDR) channels to the user logic in the user clock domain.
- Provides the possibility of overwriting the initial ADC configuration by providing an optional upper level interface that allows indirect access to the ADC’s SPI interface.
- Configures the Clock Generator to output a clock signal to the ADC with a frequency from a set list
- Performs offset and gain calibration based on coefficients specified by the user/upper level IPs.

# 3 Performance

This IP is designed to have a configurable width for the data interface and a configurable sampling rate so that it can manage the low-level communication with the Zmods enumerated in chapter 1 (Introduction). The parallel DDR data interface used to communicate with the ADC is 14 bit wide and the sampling rate has a set of 7 predefined values: 50MHz, 80MHz, 100MHz, 110MHz, 120MHz, 122.88MHz and 125MHz. The Zmod Digitizer Controller further exports to the user logic two distinct SDR channels synchronized in the ADC sampling clock domain (DcoClkOut).

# 4 Overview

Figure 1. Zmod Digitizer Controller block diagram.

The structure of the IP is presented in Figure 1. The main functionalities are divided as ADC input clock generation, data capture (data path), ADC calibration, ADC configuration (two items related to configuration functionalities will be detailed separately: the configuration state machine and the SPI controller) and Clock Generator configuration (state machine and I2C controller).

## Clocking

The IP is divided in 4 clock domains as shown in Figure 1:

            1. The system clock domain (SysClk100) clocks the ADC configuration module, the Clock Generator configuration module together with its I2C controller and the SPI controller. The frequency of this clock is expected to be 100MHz. All signals synchronous with SysClk100 have the prefix “s”.
            2. The ADC input clock (ClockGenPriRefClk) is used to clock the primitives responsible with passing the input clock to the Clock Generator which then feeds the ADC with a clock signal. All signals synchronous with ClockGenPriRefClk have the prefix “i”.
            3. The DCO clock (DcoClkIn) is generated by the ADC and is used to clock the IDDR primitives that demultiplex the ADC incoming DDR data bus through a BUFIO primitive (DcoBufioClk) and the ADC Calibration module using a BUFG primitive (DcoClkOut). All signals synchronous with the de-skewed version of DcoClkIn have the prefix “do” for DcoClkOut or “db” for DcoBufioClk.

The IP does not constrain the clocks it requires as inputs, except for the DCO clock, therefore clocks need to be constrained in the top-level design either manually or by relying on the auto-derived constraints, if using clock modifying blocks. It is the user’s responsibility to correctly configure the input clocks of this IP.

## Reset

This IP has a single asynchronous reset input with negative polarity (aRst_n) which resets the logic in all four clock domains. To assure that recovery/removal time of sequential logic is respected, the reset input is distributed to the different clock domains throughout the IP by ResetBridge modules. The ResetBridge modules are responsible with converting the asynchronous reset input in reset signals with synchronous de-assertion (RSD) for each clock domain.

The input reset (aRst_n) must be asserted for at least 2*Tslowest, where Tslowest represents the period of the slowest clock input of the IP. After applying a reset, the sRstBusy output is asserted by the IP. The user/upper level IP has to wait for sRstBusy to be de-asserted in order to safely apply a new reset to the Zmod Digitizer Controller.

## ADC Input Clock Generation

The ADC ICs (AD96xx) on the supported Zmod Digitizer modules require a differential clock as input. This IP allows a set range of frequencies for this clock while also allowing custom frequency configurations thanks to the Clock Generator that is used to feed a differential clocking signal directly to the ADC. The minimum frequency is limited to 10 MHz, while for the maximum frequency the limit is imposed by the Clock Generator’s maximum output frequency [1], the FPGA’s clocking network limitations [2] and by the ADC capabilities. This IP does not generate these clock frequencies internally, it only instantiates the IO primitives required to pass it further into the FPGA.

The Clock Generator can be configured to use one of two possible differential input reference clocks, a primary reference clock that is meant to come from the FPGA and a secondary reference clock that is hardwired to an XTAL source.

## Data Path (DataPath.vhd)

The data path consists of two stages. First, each bit of the input parallel data bus is passed to an IDDR primitive used to demultiplex the DDR interleaved format exported by the ADC (Figure 2), obtaining two SDR data channels.

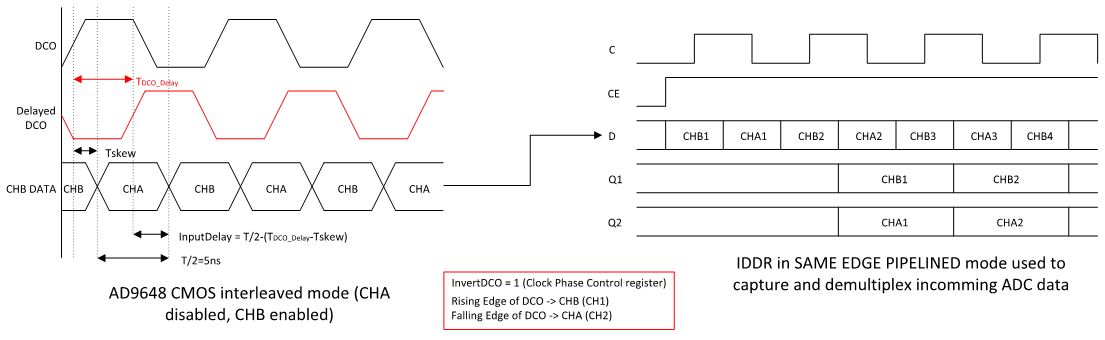
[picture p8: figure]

Figure 2. Input data channel demultiplexing

To meet timing requirements a MMCM is used for de-skew purposes. The MMCM is also used to detect the ADC’s DCO clock loss. The Data Path module is implemented as a distinct VHDL module and its parameters and ports are described below:

Table 1. Data Path module parameter description

Parameter Name | Description
kSamplingPeriod | The sampling clock period expressed in ns. The maximum value is limited to 100, while it is the user’s responsibility to determine the minimum value based on the targeted Zmod’s capabilities and the targeted FPGA’s clocking distribution network capabilities.
kADC_Width | ADC resolution (number of bits). This parameter ranges from 10 to 16.

Table 2. Data Path port description

Signal Name | Interface | Signal Type | Init State | Description
RefClk | - | I | N/A | Reference clock.
arRst | - | I | N/A | Active high reset (can be asynchronously de-asserted but synchronously asserted in the RefClk domain).
DcoClkIn | - | I | N/A | Connected directly to the Zmod’s AD96xx DCO output clock.
DcoClkOut | - | O | N/A | The Zmod’s AD96xx DCO output clock forwarded to the IP's top-level module (the de-skew block output).
doEnableAcquisition | - | I | N/A | When logic '1', this signal enables data acquisition from the ADC. This signal should be kept in logic '0' until the downstream IP (e.g. DMA controller) is ready to receive the ADC data. Once this signal has been set to logic ‘1’, it should be kept in this state and never de-asserted.
adoRst | - | I | N/A | Reset signal asynchronously de-asserted and synchronously asserted (in the DcoClkOut domain).
rDcoMMCM_LockState | - | O | N/A | MMCM Locked output signal synchronized on RefClk.
diADC_Data[kADC_Width-1 : 0] | - | I | N/A | kADC_Width bit wide DDR parallel data bus exported by ADC containing Channel1 and Channel 2 interleaved samples.
doChannelA[kADC_Width-1 : 0] | - | O | N/A | The demultiplexed ADC’s Channel A data output synchronized in the DcoClkOut domain.
doChannelB[kADC_Width-1 : 0] | - | O | N/A | The demultiplexed ADC’s Channel B data output synchronized in the DcoClkOut domain.
doDataOutValid | - | O | N/A | Channel A & B data valid indicator.

## ADC Calibration (GainOffsetCalib.vhd)

The analog front end of the Zmod Digitizer and the ADC itself inevitably distort in a certain degree the input signal. Out of these errors, the gain and offset errors are relatively easy to compensate.

Table 3. ADC Calibration module parameter descriptions.

Signal Name | Description
kWidth | ADC/DAC resolution.
kExtCalibEn | Enables the external calibration interface. Set to “true” when the IP core is expected to be interfaced with the processing system through a high level IP. Set to “false” when the core operates in stand alone mode.
kInvert | When asserted, kInvert determines the sign inversion of the data samples received. Used to compensate the physical inversion of some of the channels on the PCB at the ADC/DAC input/output on the Zmod.
kHgMultCoefStatic[17:0] | High gain multiplicative calibration coefficient. If the kExtCalibEn parameter is set to “false”, the calibration block will expect the value of the multiplicative coefficient to be passed through this parameter. If the value of kExtCalibEn parameter is “true”, this parameter is ignored, and the high level IP is expected to update the corresponding external port.
kHgAddCoefStatic[17:0] | High gain additive calibration coefficient. If the kExtCalibEn parameter is set to “false”, the calibration block will expect the value of the additive coefficient to be passed through this parameter. If the value of kExtCalibEn parameter is “true”, this parameter is ignored, and the high level IP is expected to update the corresponding external port.

Table 4. ADC Calibration module port description

Signal Name | Interface | Signal Type | Init State | Description
SamplingClk | - | I | N/A | Sampling clock. The frequency range supported is between 10 MHz and the maximum frequency supported by the Zmod/target FPGA clock distribution network.
acRst_n | - | I | N/A | Active low reset (can be asynchronously asserted but synchronously de-asserted in the sampling clock domain).
cTestMode | - | I | N/A | cTestMode is used to bypass the calibration block. When asserted, raw samples are provided on the data interface.
cExtLgMultCoef[17:0] | - | I | N/A | Low gain multiplicative coefficient external port. This port is enabled by setting the ExtCalibEn parameter to “true”.
cExtLgAddCoef[17:0] | - | I | N/A | Low gain additive coefficient external port. This port is enabled by setting the ExtCalibEn parameter to “true”.
cExtHgMultCoef[17:0] | - | I | N/A | High gain multiplicative coefficient external port. This port is enabled by setting the ExtCalibEn parameter to “true”.
cExtHgAddCoef[17:0] | - | I | N/A | High gain additive coefficient external port. This port is enabled by setting the ExtCalibEn parameter to “true”.
cGainState | - | I | N/A | Corresponding channel gain relay state. The ADC /DAC calibration module requires the gain relay state in order to apply the appropriate calibration coefficients, which are different between the low gain option and the high gain option. The relay gain state is provided by the Relay Configuration module. • 1 = High Gain (relay set). • 0 = Low Gain (relay reset).
cDataRaw[Width-1 : 0] | - | I | N/A | Input raw samples provided by the Data Path module.
cDataInValid | - | I | N/A | Data valid indicator provided by the Data Path module.
cCalibDataOut[15 : 0] | - | O | N/A | Calibrated data output. Regardless of the ADC/DAC resolution, the output of the calibration process is represented on 16 bits.
cDataCalibValid | - | O | N/A | Delayed version of cDataInValid. The same latency obtained for the calibration process (3 sampling clock cycles) is added to the input valid indicator to obtain cDataCalibValid.

In order to compensate the gain and offset errors, at manufacturing, a calibration additive constant and a calibration gain constant are computed and saved in the Zmod’s calibration memory, as described in the Zmod Digitizer Reference Manual:

, V_(in) =(N_(raw) *Range *(1+CG))/(2^13)+CA#(1)

were:

- NRaw = the 14 bit, 2's complement integer number returned by the ADC.
- Vin= the corrected value of the input voltage.
- CA = factory calibration raw additive constant stored in the Zmod’s calibration memory (for the appropriate channel and gain).
- CG = factory calibration raw gain constant stored in the Zmod’s calibration memory (for the appropriate channel and gain).
- Range = the theoretical range of the ADC channel input stage:
  - 1.086 (-1V…+1V)

Based on equation (1), the ADC raw (uncalibrated) digital code output corresponding to an input voltage Vin is:

, N_(raw) =(V_(in) *2^13)/(Range*(1+CG))-(CA*2^13)/(Range*(1+CG))#(2)

While the real range of the Zmod Digitizer is the one defined above, the specified (ideal) range of the product is ±1V. Having the calibration applied, the outputs of the Zmod Digitizer Controller should be those of an ideal ADC having these ideal ranges:

, N_(calib) =(V_(in) *2^13)/(Range_(ideal)) #(3)

were Rangeideal is 1. From (2) and (3) one can obtain:

, N_(calib) =N_(raw) *(Range*(1+CG))/(Range_(ideal))+(CA*2^13)/(Range_(ideal))#(4)

This IP works, however, with a fractional representation of the ADC’s output code. Equation (4) becomes:

, N_(calib_(fract)) =N_(raw_(fract)) *(Range*(1+CG))/(Range_(ideal))+(CA)/(Range_(ideal))#(5)

Considering that the inputs of the GainOffsetCalib module are labeled cDataRaw, while the outputs are labeled cDataCalib, based on (5), the relation between the outputs and the inputs is:

, cDataCalib=cDataRaw*CoefMult+CoefAdd#(6)

where:

, CoefMult=(Range*(1+CG))/(Range_(ideal))#(7)

, CoefAdd=(CA)/(Range_(ideal))#(8)

CoefMult and CoefAdd are fractional numbers computed for each channel and each gain option. CoefMult and CoefAdd are further scaled so that they can be passed as integer numbers to the IP:

, CoefMult_(scaled) =(Range*(1+CG)*2^16)/(Range_(ideal))#(9)

, CoefAdd_(scaled) =(CA*2^17)/(Range_(ideal))#(10)

The numerical representation of the operands of the calibration process is illustrated in Figure 3. The scaled version of CoefMult and CoefAdd are named “processed calibration coefficients” and these are the constants required by the GainOffsetCalib module, not the “raw coefficients” stored in the Zmod’s calibration memory. One can note (Figure 3) that the GainOffsetCalib converts the processed calibration coefficients back to their fractional representation.

Figure 3: Calibration process

The multiplicative and additive coefficients are passed by the upper layer IP Core if the Zmod Digitizer Controller is used in a processor system (the external calibration interface is enabled) or they can be passed as IP core parameters otherwise. The user can obtain the calibration coefficients by booting the Eclypse board with the Linux image provided at https://github.com/Digilent/Eclypse-Z7/releases and run the "decutil enum" command in the command line. The Zmod has to be plugged in one of the Eclypse’s board SYZYGY ports. The Digilent Eclypse Utility (decutil) provides a command line interface for discovering information about the features and configuration of an Eclypse platform board. Decutil reports the factory raw calibration parameters and processed calibration parameters as show in Figure 4. This IP works with the processed calibration coefficients. More information about the Digilent Eclypse Utility can be found at https://reference.digilentinc.com/_media/reference/programmable-logic/eclypse-z7/decutil.1.pdf.

For simplicity in Figure 1 only one ADC Calibration module is represented. In the actual implementation, a distinct ADC Calibration module is used for each channel. The outputs of the calibration module are concatenated on the AXI Stream output (master) Data interface in the IP’s top-level module. Since the data port of the Data interface is 32 bit wide, regardless of the ADC resolution (kADC_Width), the most significant 16 relevant bits are selected out of the calibration result, as shown in Figure 3.


Processed calibration

coefficients

Raw calibration

coefficients

Figure 4: Obtaining calibration parameters from decutil

## ADC Configuration (ConfigADC.vhd)

The ADC Configuration block sends a predefined list of SPI commands to the Zmod Digitizer, performing the ADC initialization, and manages the SPI Indirect Access Port (IAP). The ports and parameters of the ADC configuration block, which is implemented as a distinct VHDL module are listed below:

Table 5. ADC Configuration parameter description

Parameter Name | Description
kZmodID | Parameter identifying the targeted Zmod. See Table 13 for more details.
kDataWidth | The number of data bits for the data phase of the transaction: only 8 data bits currently supported, parameter provided for future development.
kCommandWidth | The number of bits of the command phase of the SPI transaction.

Table 6. ADC Configuration port description

Signal Name | Interface | Signal Type | Init State | Description
SysClk100 | - | I | N/A | 100MHz input clock signal.
asRst_n | - | I | N/A | Active low reset (can be asynchronously asserted but synchronously de-asserted).
sADC_Sclk | SPI | O | N/A | Output SPI clock. Signal managed by the SPI controller. More details in section 4.9.
sADC_SDIO | SPI | IO | N/A | 2 Wire SPI interface SDIO signal. Signal managed by the SPI controller. More details in section 4.9.
sADC_CS | SPI | O | N/A | 2 Wire SPI interface CS signal. Signal managed by the SPI controller. More details in section 4.9.
sInitDoneADC | - | O | N/A | Flag indicating when the Zmod’s ADC initialization is complete.
sConfigError | - | O | N/A | This flag is asserted if the ADC initialization fails. An IP reset is required to clear this flag.
sConfigADCEnable | - | I | N/A | ADC initialization enable signal. Configuration of the ADC over SPI should be done after sConfigADCEnable is asserted which only happens after the CDCE clock generator is configured and the PLL inside the CDCE is locked, otherwise the ADC configuration state machine should be kept in reset.
sCmdTxAxisTdata[31:0] | SPI IAP | I | N/A | IAP command TX interface (AXI Stream) data port.
sCmdTxAxisTvalid | SPI IAP | I | N/A | IAP command TX interface (AXI Stream) valid signal.
sCmdTxAxisTready | SPI IAP | O | N/A | IAP command TX interface (AXI Stream) ready signal.
sCmdRxAxisTdata[31:0] | SPI IAP | O | N/A | IAP command RX interface (AXI Stream) data port.
sCmdRxAxisTvalid | SPI IAP | O | N/A | IAP command RX interface (AXI Stream) valid signal.
sCmdRxAxisTready | SPI IAP | I | N/A | IAP command RX interface (AXI Stream) ready signal.

Once the initialization is complete, the state machine of the ADC configuration block enters the idle state where it monitors if there is any valid data on the upper level SPI command interface named the SPI Indirect Access port (IAP). After executing the requested SPI transfers, the state machine passes the received SPI data (for read commands) and returns to the idle state. The SPI IAP is optional, and it can be enabled by setting the kExtCmdInterfaceEn to “true”. It is designed to interface with 2 AXI StreamFIFOs, one that stores commands to be transmitted (command queue TX FIFO) and one to store the received data (command RX FIFO). Thus, the IAP consists of two AXI Stream interfaces: the IAP command TX interface and the IAP RX command interface. Each element of the command queue should be represented on 32 bits, having the following format:

31 24 | 23 | 22 21 | 20 8 | 7 0
- | Read/Write | Width | Address | Data

Bits | Field Name | Description
23 | Read/Write | Write this bit to 1 for a read command and to 0 for a write command
22-21 | Width | Only 1 byte SPI transfers are supported. This field should be always 0h.
20-8 | Address | ADC SPI register address
7-0 | Data | Data byte to be sent to the AD9648. Ignored for read operations

The ADC Configuration state machine, when in the idle state, monitors the valid signal of the IAP command TX interface (sCmdTxAxisTvalid) and, if asserted and if the SPI controller can process a new command (not busy), the ready signal of the IAP command TX interface is asserted for one SysClk100 clock cycle. Write commands only consist of a single transaction on the IAP command TX interface. For read commands, after passing the register read request to the SPI controller and the request successfully completes, the ADC Configuration state machine asserts the valid signal of the IAP command RX interface (sCmdRxAxisTvalid) and places the register read data on the data port of the interface (sCmdRxAxisTdata). The ADC Configuration state machine waits for the upper layer IP to assert the ready signal on the IAP command interface (sCmdRxAxisTready) before it transitions to the idle state.

The initialization configuration command sequence is listed below. After configuring each register, the register data is read back and checked against the expected value in order to determine any SPI transaction error.

1. SPI Port config register: Soft Reset (Address: 00h; Data: 3C).
2. Chip ID Register: Check ID (Read, Address: 01h; Data: -).
3. Device Index Register: Select CHA (Address: 05h; Data: 01h).
4. Power modes Register: Digital reset (Address: 08h; Data: 03h).
5. Output mode register: Output port logic type -> CMOS 1.8V, output interleave enable, disable port (port A), output invert disable, 2’s complement (Address: 14h; Data: 31h).
6. Device Index Register: Select CHB (Address: 05h; Data: 01h).
7. Power modes Register: Digital reset (Address: 08h; Data: 03h).
8. Output mode register: Output port logic type -> CMOS 1.8V, output interleave enable, enable port (port B), output invert disable, 2’s complement (Address: 14h; Data: 21h).
9. Device Index Register: Select none (Address: 05h; Data: 00h).
10. Clock Phase Control register: Invert DCO (Address: 16h; Data: 80h).
11. Clock Divide register: Divide input clock by ADC_ClkDiv (Address: 0Bh; Data: ADC_ClkDiv).
12. Overrange Control register: Disable overrange output (Address: 2Ah; Data: 00h).
13. Output Adjust register: DCO and DATA 2X drive strength (Address: 15h; Data: 00h).
14. Output delay register: 1.12ns delay added to DCO (Address: 17h; Data: 81h).
15. Sync control register: SYNC enable, continuous SYNC (Address: 3Ah; Data: 02h).
16. Device Index Register: Select CHA (Address: 05h; Data: 01h).
17. Power modes: Normal operation (Address: 08h; Data: 00h).
18. Device Index Register: Select CHB (Address: 05h; Data: 02h).
19. Power modes: Normal operation (Address: 08h; Data: 00h).
20. Device Index Register: Select none (Address: 05h; Data: 00h).

## SPI Controller (ADI_SPI.vhd)

The SPI controller is designed to carry out basic register access over the Analog Devices 2 wire SPI interface. The controller’s parameters and ports are listed below:

Table 7. SPI controller parameter description

Parameter Name | Description
kSysClkDiv | The sSPI_Clk signal is obtained by dividing SysClk100 to 2kSysClkDiv.
kDataWidth | The number of data bits for the data phase of the transaction: only 8 data bits currently supported, parameter provided for future development.
kCommandWidth | The number of bits of the command phase of the SPI transaction.

Table 8. SPI controller port description

Signal Name | Interface | Signal Type | Init State | Description
SysClk100 | - | I | N/A | 100MHz input clock signal.
asRst_n | - | I | N/A | Active low reset (can be asynchronously asserted but synchronously de-asserted).
sSPI_Clk | SPI | O | N/A | Output SPI clock [4] divided from SysClk100. Connected directly to the corresponding Zmod port.
sSDIO | SPI | IO | N/A | 2 Wire SPI interface SDIO signal [4]. Connected directly to the corresponding Zmod port.
sCS | SPI | O | N/A | 2 Wire SPI interface CS signal [4]. Connected directly to the corresponding Zmod port.
sApStart | - | I | N/A | A pulse on this input initiates the transfers. When asserted, the inputs of the upper layer interface are also registered.
sRdData[kDataWidth-1 : 0] | - | O | N/A | SPI register read received data
sWrData[kDataWidth-1 : 0] | - | I | N/A | SPI register write data.
sAddr[kCommandWidth - 4:0] | - | I | N/A | SPI instruction phase address.
sWidth[1:0] | - | I | N/A | SPI instruction phase word length. The only value currently supported is 0 (1 data byte transferred).
sRdWr | - | I | N/A | Encodes the requested transaction type: ‘1’ - read transaction. ‘0’ – write transaction.
sDone | - | O | N/A | Indicates that the operation requested has completed and that the data placed on the sRdData port is valid.
sBusy | - | O | N/A | Indicates when a new command can be processed. It is de-asserted only when the internal state machine of the SPI Controller is in the idle state and it is asserted at any other time. sApStart is ignored while this signal is asserted.

An SPI transaction is triggered by generating a pulse on the sApStart input. When the pulse is detected, the inputs of the upper layer interface are also registered. The sRdWr signal encodes the type of the transaction (read/write). The SPI controller further constructs the command word and the data word based on the module’s inputs and formats them on the SPI bus as requested by the Analog Devices’ specifications [4]. For read operations, the received data is outputted on the sRdData port and can be read by the upper layer module when the sDone signal pulses high. When the SPI controller returns to the idle state and is ready to process new commands, the sBusy output signal is de-asserted. The sApStart signal is ignored while sBusy is asserted. The width of the command word is configurable through the kCommandWidth generic. The frequency of the SPI output clock is obtained by dividing the controller’s input clock frequency by a factor of 2kSysClkDiv (kSysClkDiv is also a generic). Only single byte data transfers are currently supported. More details about the SPI interface of the supported ADCs can be found in [4].

## Clock Generator Configuration (ConfigClockGen.vhd)

The Clock Generator Configuration block sends a predefined list of I2C commands to the Clock Generator that feeds the ADC a differential clocking signal source. From the IP GUI the user can select from a set of frequency configurations. The possibility of adding custom frequency configurations is open to the user, however, it requires advanced knowledge of the IP, the clock generator and the proprietary software that must be used to generate said custom frequency configurations.

It is the user’s responsibility to ensure that after changing the sampling frequency from inside the IP GUI they also they also change the calibration coefficients to match the desired sampling frequency. Each supported frequency configuration has its own calibration coefficients stored inside an EEPROM present on the Zmod. For more information please consult the Zmod Digitizer’s Reference Manual, more specifically the paragraph about Calibration.

The REFSEL signal is used to select between the two reference clock inputs of the Clock Generator, a value of ‘0’ selects the secondary reference input while a value of ‘1’ selects the primary one which comes from the FPGA and is a tri-level output signal. This reference clock selection can also be done irrespective of the value of the signal by writing 0x02 for SECREF or 0x03 for PRIREF to the REFSEL_SW register bit field of R2.

The set values of output frequencies provided all use the XTAL input as reference clock and that is not dependent on the value of the REFSEL signal because the Clock Generator’s REFSEL_SW register bit field is set to 0x02 and the REFSEL signal is kept in tristate.

The configuration of the Clock Generator registers can also be done via its internal 2 Page EEPROM and the pages can be written and rewritten over I2C. The signal that acts as page select is called HW_SW_CTRL and is also a tri-level output pin.

By default, the Clock Generator is configured to run in Fall-Back Mode (0x67 in 7-bit format or 0xCE in 8-bit format), a mode in which the I2C serial interface is always enabled and the configurations written inside the EEPROM are ignored. This is done by forcing the REFSEL and HW_SW_CTRL output signals to be in High-Z state through the use of an OBUFT FPGA primitive. This means that the user should not add any kind of pull-up or pull-down on those signals as it would disrupt their functionality. The other modes involve its configuration being read from an internal factory programmed 2 Page EEPROM which can have frequency configurations unsupported by this IP.

Table 9. Clock Generator Configuration parameter description

Parameter Name | Description
kCDCE_SimulationConfig | Clock Generator I2C parameter for enabling a shortened configuration for simulation purposes.
kCDCE_SimulationCmdTotal | Clock Generator I2C shortened configuration number of commands to send over I2C for simulation purposes.
kCDCEI2C_Addr | Clock Generator 7-bit I2C address (0x67 (Fall-Back Mode), 0x68(Default Mode), 0x69).
kRefSel | Clock Generator input reference clock selection parameter ('0' selects SECREF(XTAL) and '1' selects PRIREF(FPGA)). Only matters when the Clock Generator is not in Fall-Back Mode.
kHwSwCtrlSel | Clock Generator EEPROM Page selection parameter ('0' selects Page 0 and '1' selects Page 1). Only matters when the Clock Generator is not in Fall-Back Mode.
kFreqSel | Parameter identifying the CDCE output frequency with SECREF(XTAL) as reference frequency: -- 0 -> 122.88MHz -- 1 -> 50MHz -- 2 -> 80MHz -- 3 -> 100MHz -- 4 -> 110MHz -- 5 -> 120MHz -- 6 -> 125MHz

Table 10. Clock Generator Configuration port description

Signal Name | Interface | Signal Type | Init State | Description
RefClk | - | I | N/A | 100MHz input clock signal.
arRst | - | I | N/A | Active high reset (can be synchronously asserted but asynchronously de-asserted).
rInitConfigDoneClockGen | - | O | N/A | Clock Generator configuration done successfully signal.
aCG_PLL_Lock | - | I | N/A | Clock Generator PLL lock signal sent via the GPIO1 or GPIO4 port.
rPLL_LockClockGen | - | O | N/A | Clock Generator PLL lock signal sent via the GPIO1 or GPIO4 port and synchronized in the RefClk domain.
rConfigADCEnable | - | O | N/A | rConfigADCEnable is used to hold the ConfigADC module in reset until the Clock Generator is configured and locked.
REFSEL | - | O | Z | Clock Generator reference selection signal (low selects SECREF (XTAL) and high selects PRIREF (FPGA)). When High-Z selection is determined by register value.
HW_SW_CTRL | - | O | Z | Clock Generator EEPROM Page selection signal (low selects Page 0 and high selects Page 1). When High-Z selection is determined by register value.
rPDNout_n | - | O | L | Clock Generator power down signal. Resets the internal circuitry and is used in the initial power-up sequence.
s_scl_i | I2C | I | Z | I2C Serial Clock Input from 3-state buffer.
s_scl_o | I2C | O | L | I2C Serial Clock Output to 3-state buffer.
s_scl_t | I2C | T | N/A | I2C Serial Clock Output Enable to 3-state buffer.
s_sda_i | I2C | I | Z | I2C Serial Data Input from 3-state buffer.
s_sda_o | I2C | O | L | I2C Serial Data Output to 3-state buffer.
s_sda_t | I2C | T | N/A | I2C Serial Data Output Enable to 3-state buffer.

# 5 IP Top-Level Parameter Description

Table 11. IP core parameter descriptions.

Signal Name | Description
kZmodID | Parameter identifying the targeted Zmod. See Table 13 for more details.
kADC_Width | ADC resolution (number of bits). It is automatically computed based on kZmodID.
kExtCalibEn | Enables the external calibration interface. Set to “true” when the IP core is expected to be interfaced with the processing system through a high level IP which will send the calibration constants to the Zmod Digitizer Controller. Set to “false” when the core operates in stand alone mode.
kExtCmdInterfaceEn | Enables the upper layer IP SPI configuration interface. Set to “true” when the IP core is expected to be interfaced with the processing system through a high level IP. This will enable the processor to access the Zmod Digitizer SPI interface and to change the ADC settings if desired. Set to “false” when initial configuration described in Section 4.8 is sufficient.
kCh1HgMultCoefStatic[17:0] | Channel1 high gain multiplicative calibration coefficient. If the kExtCalibEn parameter is set to “false”, the ADC Calibration block will expect the value of the multiplicative coefficient to be passed through this parameter. If the value of kExtCalibEn parameter is “true”, this parameter is ignored, and the high level IP is expected to update the corresponding external port.
kCh1HgAddCoefStatic[17:0] | Channel1 high gain additive calibration coefficient. If the kExtCalibEn parameter is set to “false”, the ADC Calibration block will expect the value of the additive coefficient to be passed through this parameter. If the value of kExtCalibEn parameter is “true”, this parameter is ignored, and the high level IP is expected to update the corresponding external port.
kCh2HgMultCoefStatic[17:0] | Channel2 high gain multiplicative calibration coefficient. If the kExtCalibEn parameter is set to “false”, the ADC Calibration block will expect the value of the multiplicative coefficient to be passed through this parameter. If the value of kExtCalibEn parameter is “true”, this parameter is ignored, and the high level IP is expected to update the corresponding external port.
kCh2HgAddCoefStatic[17:0] | Channel2 high gain additive calibration coefficient. If the kExtCalibEn parameter is set to “false”, the ADC Calibration block will expect the value of the additive coefficient to be passed through this parameter. If the value of kExtCalibEn parameter is “true”, this parameter is ignored, and the high level IP is expected to update the corresponding external port.
kCG_SimulationConfig | Clock Generator I2C shortened config for simulation purposes.
kCG_SimulationCmdTotal | Clock Generator I2C shortened configuration number of commands to send over I2C for simulation purposes, range should have been 0 to kCDCE_RegNrZeroBased := kCDCE_RegNrZeroBased, however Vivado IP GUI does not accept expressions.
kCGI2C_Addr | Clock Generator 7-bit I2C config address (0x67 (Fall-Back Mode), 0x68(Default Mode), 0x69).
kRefSel | Clock Generator input reference clock selection parameter ('0' selects SECREF(XTAL) and '1' selects PRIREF(FPGA)). Only relevant when the Clock Generator is not in Fall-Back Mode.
kHwSwCtrlSel | Clock Generator EEPROM Page selection parameter ('0' selects Page 0 and '1' selects Page 1). Only relevant when the Clock Generator is not in Fall-Back Mode.
kCDCEFreqSel | Parameter identifying the CDCE output frequency with SECREF(XTAL) as reference frequency, range should have been 0 to CDCE_I2C_Cmds'length, however Vivado IP GUI does not accept expressions: -- 0 -> 122.88MHz -- 1 -> 50MHz -- 2 -> 80MHz -- 3 -> 100MHz -- 4 -> 110MHz -- 5 -> 120MHz -- 6 -> 125MHz
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

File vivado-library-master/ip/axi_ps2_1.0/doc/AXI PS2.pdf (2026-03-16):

1300 Henley Court
Pullman, WA 99163
509.334.6306
www.digilentinc.com

## AXI PS/2 1.0 IP Core User Guide

Revised February 13, 2018; Author Sergiu Arpadi

DOC#: 516-004 | Copyright Digilent, Inc. All rights reserved.
Other product and company names mentioned may be trademarks of their respective owners. | Page 1 of 7

## 1 Introduction

This user guide describes the Digilent AXI PS/2 Intellectual Property. The purpose of this IP is to implement a software controllable PS/2 host controller.

## 2 Features

- Contains two 16-byte deep FIFOs; one for TX and one for RX
- Generates a level sensitive interrupt depending on the IER register.
- Implements 7 AXI4 Lite registers for data, control, status and interrupt configuration.

## 3 Performance

The PS/2 IP Core is an AXI4 Lite PS/2 host controller capable of interfacing with either a mouse or a keyboard.

Sending data to a device is done by writing one byte at a
time to the TX data register. The core then passes the bytes to the TX FIFO and determines when to send them to the PS/2 controller where they are serialized.

When a byte is received from the PS/2 device it is deserialized and stored in the RX FIFO from where it is passed to the RX data AXI4 Lite register.

An interrupt can be generated for certain situations like PS/2 communication errors or FIFO occupancy.

The core can also be reset from the software using the software reset register.

IP quick facts

Supported device
families | Zynq®-7000, 7 series
Supported user interfaces | Xilinx: AXI4 Lite,
| PS/2

Provided with core

Design files | VHDL
Simulation model | N/A
Constraints file | XDC
Software driver | Standalone

Tested design flows

Design entry | Vivado™ Design
| Suite 2016.4
Synthesis | Vivado Synthesis
| 2016.4

AXI PS/2 1.0 IP Core User Guide

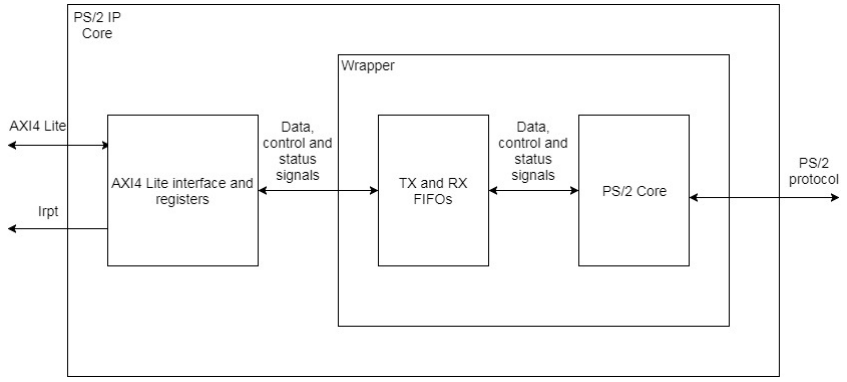
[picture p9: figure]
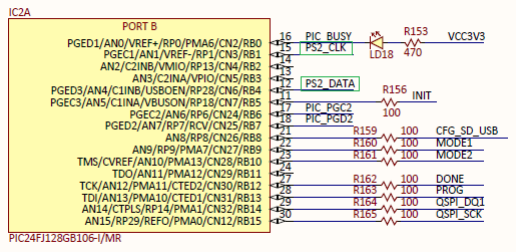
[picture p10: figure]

Copyright Digilent, Inc. All rights reserved.
Other product and company names mentioned may be trademarks of their respective owners. | Page 2 of 7

## 4 Overview

Figure 1. AXI PS/2 block diagram.

The IP consists of three main blocks. The AXI4 Lite block manages the control and status registers and is also in charge of generating the interrupt. The two FIFOs act as a buffer between this block and the PS/2 core where the PS/2 interface is implemented.
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

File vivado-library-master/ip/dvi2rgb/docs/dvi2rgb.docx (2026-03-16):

# 1 Introduction

IP quick facts
Supported device families | Zynq®-7000, 7 series
Supported user interfaces | Xilinx®: IIC, vid_io Digilent: TMDS

Provided with core
Design files | VHDL
Simulation model | VHDL Behavioral
Constraints file | XDC
Software driver | N/A

Tested design flows
Design entry | Vivado™ Design Suite 2018.2
Synthesis | Vivado Synthesis 2018.2
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

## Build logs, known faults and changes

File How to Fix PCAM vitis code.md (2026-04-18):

How to Fix PCAM vitis code

## Camera passthrough bring-up checklist

1. Create the app component on the **correct platform/domain**
   Use:

   * platform: `camera_motor_v2`
   * domain: `standalone_ps7_cortexa9_0`

2. Copy in the Digilent passthrough source tree
   The app needed the same source structure as the working passthrough app:

   * `main.cc`
   * `platform/`
   * `ov5640/`
   * `hdmi/`
   * `MIPI_CSI_2_RX_v1_0/`
   * `MIPI_D_PHY_RX_v1_0/`
   * `xparams_compat.h`
   * `assert_filename_fix.h`

3. Fix the compile source list in `UserConfig.cmake`
   Keep only the files actually needed to build the app.
   The passthrough app does **not** need the CSI/DPHY self-test files. Your earlier builds were compiling those extra self-test sources while also compiling the main video sources. 

   Use this source list:

   * `main.cc`
   * `MIPI_CSI_2_RX_v1_0/src/MIPI_CSI_2_RX.c`
   * `MIPI_D_PHY_RX_v1_0/src/MIPI_D_PHY_RX.c`
   * `ov5640/OV5640.cpp`
   * `platform/platform.c`

4. Fix the `__FILENAME__` build break
   The big compile failure came from the bad compiler define
   `-D__FILENAME__='__FILE__'`, which showed up directly in your build logs and caused the `Xil_Assert` type mismatch inside `OV5640.cpp` / `VideoOutput.h`. 
   `Xil_Assert` expects a filename pointer, not an integer-like character constant. ([AMD Documentation][1])

5. Keep `assert_filename_fix.h` and use it the right way
   The header itself was fine.
   The fix was to force-include it at **compile time** so `__FILENAME__` becomes `__FILE__`.

6. Put the forced include in `USER_COMPILE_OTHER_FLAGS`, not in linker flags
   One of the failed attempts had the `-include ${CMAKE_SOURCE_DIR}/assert_filename_fix.h` line in `USER_LINK_OTHER_FLAGS`, which does nothing for compiling `OV5640.cpp`. Your pasted `UserConfig.cmake` showed exactly that. 

   The working place is:

   * `USER_COMPILE_OTHER_FLAGS`

7. Clean hard after changing `UserConfig.cmake`
   After changing compile flags:

   * delete the app `build` folder
   * rebuild the app

   Otherwise stale generated files can keep reusing old bad settings.

8. Make sure the launch config points to the **actual ELF that was built**
   At one point Vitis tried to download `camera_passthrough.elf`, but the build logs showed the target being built as `pcam_passthrough.elf`. The launch config has to point to the real generated ELF, not a guessed filename. 
   AMD’s run flow is driven by the launch configuration for the selected application component. ([AMD Documentation][2])

9. Use `ps497view1

10. Use `ps7_init.tcl` for board initialization
    For Zynq run/debug launch configurations, `ps7_init.tcl` is the PS init script used by([AMD Customer Community][3])teturn319835search5

11. In the launch config, keep the normal Zynq bring-up boxes enabled
    For your working setup, the important run settings were:

* correct bitstream
* correct ELF
* correct `ps7_init.tcl`
* `Program Device` enabled
* `Reset Entire System` enabled

11. If the Flow Navigator **Run** button is gray, use the **Debug view play button**
    That is still a valid way to launch the app. AMD documents that running is controlled through the application’s launch configuration, and after a run you should terminate the se([AMD Documentation][2])rch0turn950497view1

12. If Vitis gets weird, restarting Vitis can clear stale run/debug state
    That is what got your `camera_passthrough` launch moving again.

## Minimal “known good” final state

For future test runs, your known good state is:

* `camera_passthrough` app builds successfully
* `UserConfig.cmake` compile sources only include the 5 real source files
* `assert_filename_fix.h` is compile-included
* no stale bad `__FILENAME__` define in the compile path
* launch config points at the real built ELF
* launch config uses `ps7_init.tcl`
* run from Debug-view play button if Flow Run is gray

## Fast retry procedure

When you want to rerun later, do this in order:

1. Open the correct workspace.
2. Select `camera_passthrough`.
3. Rebuild the app.
4. Open launch config.
5. Verify:

   * bitstream path
   * ELF path
   * `ps7_init.tcl`
6. Plug in board, Pcam, HDMI, UART.
7. Click play in Debug view.
8. After stopping, terminat([AMD Documentation][4])citeturn950497view1

set(USER_COMPILE_DEFINITIONS
)

set(USER_UNDEFINED_SYMBOLS
"__clang__"
)

set(USER_INCLUDE_DIRECTORIES
)

set(USER_COMPILE_SOURCES
"main.cc"
"MIPI_CSI_2_RX_v1_0/src/MIPI_CSI_2_RX.c"
"MIPI_D_PHY_RX_v1_0/src/MIPI_D_PHY_RX.c"
"ov5640/OV5640.cpp"
"platform/platform.c"
)

set(USER_COMPILE_OTHER_FLAGS
"-include ${CMAKE_SOURCE_DIR}/assert_filename_fix.h"
)

set(USER_LINK_OTHER_FLAGS
)

[1]: https://docs.amd.com/r/en-US/oslib_rm/Xil_Assert "Xil_Assert - Xil_Assert - 2025.2 English - UG643"
[2]: https://docs.amd.com/r/2024.2-English/ug1400-vitis-embedded/Launch-Configurations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 "Launch Configurations - 2024.2 English - UG1400"
[3]: https://adaptivesupport.amd.com/s/article/65956?utm_source=chatgpt.com "65956 - Zynq - How to make modifications to the ps7_init.tcl ..."
[4]: https://docs.amd.com/r/2024.2-English/ug1400-vitis-embedded/Running-the-Application-Component "Running the Application Component - Running the Application Component - 2024.2 English - UG1400"

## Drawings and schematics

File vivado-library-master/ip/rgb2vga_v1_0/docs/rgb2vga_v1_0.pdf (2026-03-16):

1300 Henley Court
Pullman, WA 99163
509.334.6306
www.digilentinc.com

## RGB-to-VGA 1.0 IP Core User Guide

Revised April 23, 2015; Author Elod Gyorgy

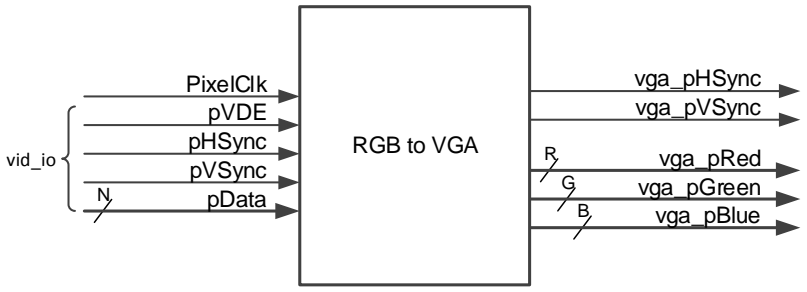
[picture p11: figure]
RGB to VGA; vga_pRed vga_pGreen vga_pBlue; vga_pHSync vga_pVSync; PixelClk pVDE pHSync pVSync pData; vid_io

DOC#: 506-031 | Copyright Digilent, Inc. All rights reserved.
Other product and company names mentioned may be trademarks of their respective owners. | Page 1 of 2

## 1 Overview

This user guide describes the Digilent RGB-to-VGA Intellectual Property. This IP accepts a Xilinx vid_io input and outputs an independently customizable color depth, properly blanked RGB pixel bus to connect to a VGA DAC. On Digilent boards the outputs directly connect to the on-board resistor ladder that serves as VGA DAC. The supported color depth varies between boards and the IP should be configured to match it.

## 2 Performance

The IP itself does not include timing constrains. PixelClk is still expected to be period-constrained from outside.

## 3 Port descriptions

Figure 1. IP top-level diagram.

The signals of the RGB-to-VGA Core are listed and described in Table 1.

IP quick facts

Supported device
families | Zynq®-7000, 7 series

Supported user
interfaces | Xilinx: vid_io

Provided with core

Design files | VHDL
Simulation model | VHDL Behavioral
Constraints file | N/A
Software driver | N/A

Tested design flows

Design entry | Vivado™ Design
| Suite 2014.4
Synthesis | Vivado Synthesis
| 2014.4

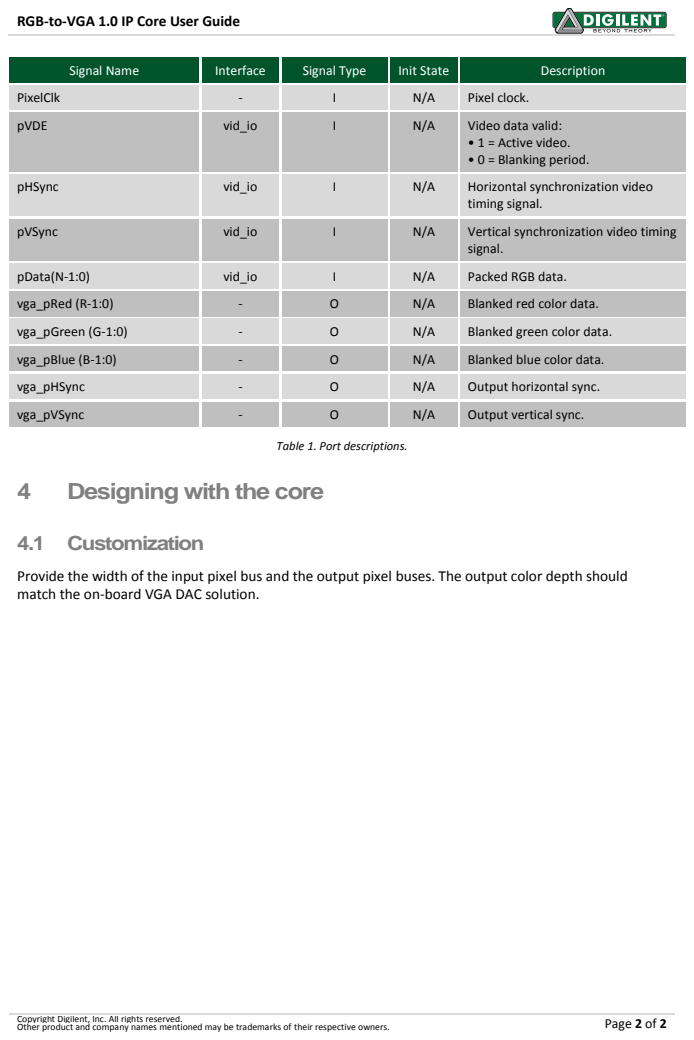
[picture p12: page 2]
Other product and company names mentioned may be trademarks of their respective owners.; Page 2 of 2; Signal Name; Interface; Signal Type; Init State; Description; PixelClk; Pixel clock.; pVDE; vid_io; Video data valid:; • 1 = Active video. • 0 = Blanking period.; pHSync; Horizontal synchronization video; timing signal.; pVSync; Vertical synchronization video timing; signal.; pData(N-1:0); Packed RGB data.; vga_pRed (R-1:0); Blanked red color data.; vga_pGreen (G-1:0)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

RGB-to-VGA 1.0 IP Core User Guide

Table 1. Port descriptions.

4 Designing with the core

Provide the width of the input pixel bus and the output pixel buses. The output color depth should
match the on-board VGA DAC solution.

Copyright Digilent, Inc. All rights reserved.

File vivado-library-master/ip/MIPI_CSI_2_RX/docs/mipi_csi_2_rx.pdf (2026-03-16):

1300 Henley Court
Pullman, WA 99163
509.334.6306
www.digilentinc.com

## MIPI CSI-2 Receiver 1.1 IP Core User Guide

Revised September 12, 2018; Author Elod Gyorgy

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

## 1 Introduction

This user guide describes the Digilent MIPI CSI-2 Receiver Intellectual Property. This IP is compatible with CSI-2 1.0 specifications and supports decoding selected pixel formats and packing data into an AXI-Stream. It pairs up with a MIPI D-PHY Receiver IP over the standard PHY Protocol Interface (PPI) to source a video subsystem.

## 2 Features

- Single or dual lane support
- RAW10 support
- Four pixels per beat AXI-Stream output for high bandwidth applications
- Xilinx interfaces used: AXI4-Lite, AXI-Stream, rx_mipi_ppi_if_rtl:1.0

## 3 Performance

The IP has been tested in dual-lane configuration with an 84 MHz PPI high-speed byte clock (RxByteClkHS) and 150 MHz AXI-Stream clock (video_aclk).

## 4 Resource Utilization

Device | Configuration

Resource

| LUT | FF | BRAM | URAM | DSP

xc7z020clg400-1

AXI-Lite
Interface | 430 | 693 | 2.5 | 0 | 0

IP quick facts

Supported device
families | Zynq®-7000, 7 series
Supported user interfaces | Xilinx®: AXI4-Lite,
| AXI-Stream,
| rx_mipi_ppi

Provided with core

Design files | VHDL
Simulation model | VHDL Behavioral
Constraints file | XDC
Software driver | standalone

Tested design flows

Design entry | Vivado™ Design
| Suite 2017.4
Synthesis | Vivado Synthesis
| 2017.4

## 5 Overview

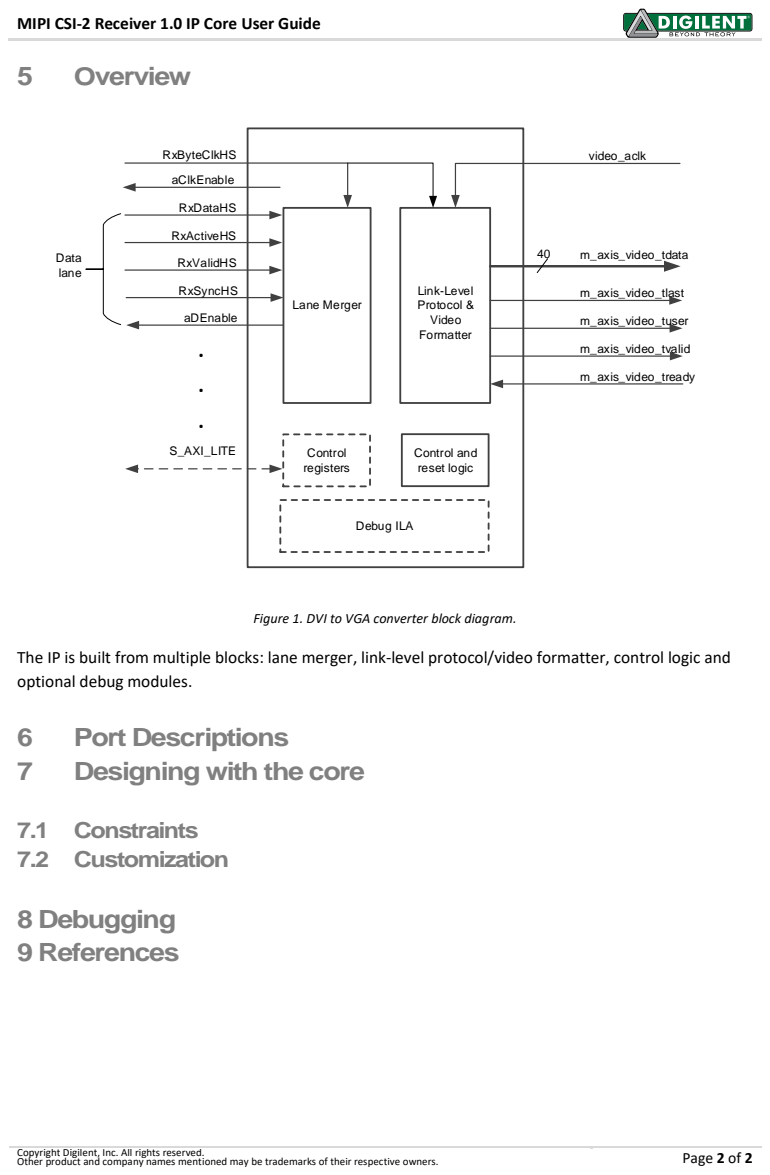
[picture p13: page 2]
Other product and company names mentioned may be trademarks of their respective owners.; Page 2 of 2; Control and reset logic; Lane Merger; Control registers; video_aclk; Debug ILA; RxByteClkHS; RxDataHS; RxActiveHS; RxValidHS; RxSyncHS; aDEnable; aClkEnable; Data lane; Link-Level Protocol & Video Formatter; m_axis_video_tdata; m_axis_video_tlast; m_axis_video_tuser; m_axis_video_tvalid; m_axis_video_tready; S_AXI_LITE; 7.1 Constraints 7.2 Customization; 8 Debugging 9 References

MIPI CSI-2 Receiver 1.0 IP Core User Guide

Figure 1. DVI to VGA converter block diagram.

The IP is built from multiple blocks: lane merger, link-level protocol/video formatter, control logic and
optional debug modules.

6 Port Descriptions
7 Designing with the core

Copyright Digilent, Inc. All rights reserved.

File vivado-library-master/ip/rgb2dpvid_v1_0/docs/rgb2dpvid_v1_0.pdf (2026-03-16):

## RGB-to-DPVID 1.0 IP Core User Guide

## 1 Introduction

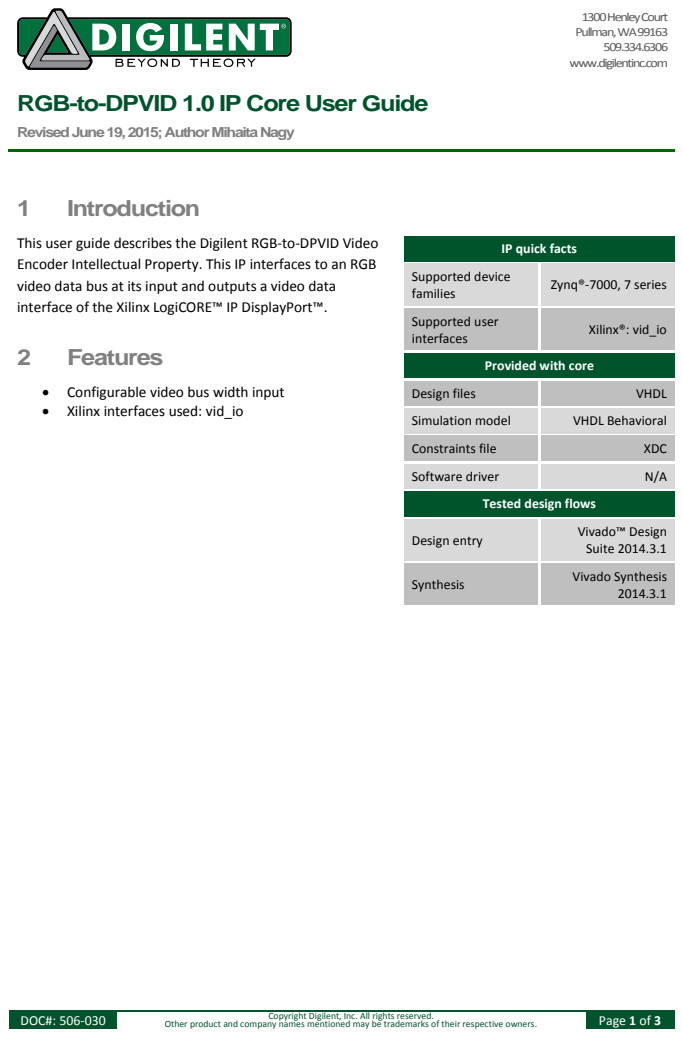
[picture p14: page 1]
DOC#: 506-030; Copyright Digilent, Inc. All rights reserved.; Other product and company names mentioned may be trademarks of their respective owners.; Page 1 of 3; 2 Features; Supported device; families; Zynq®-7000, 7 series; Supported user; interfaces; Xilinx®: vid_io; Design files; VHDL; Simulation model; VHDL Behavioral; Constraints file; XDC; Software driver; Design entry; Vivado™ Design; Suite 2014.3.1; Synthesis; Vivado Synthesis

1300 Henley Court
Pullman, WA 99163
www.digilentinc.com

Revised June 19, 2015; Author Mihaita Nagy

This user guide describes the Digilent RGB-to-DPVID Video
Encoder Intellectual Property. This IP interfaces to an RGB
video data bus at its input and outputs a video data
interface of the Xilinx LogiCORE™ IP DisplayPort™.

IP quick facts

Provided with core

• Configurable video bus width input
• Xilinx interfaces used: vid_io

Tested design flows

## 3 Overview

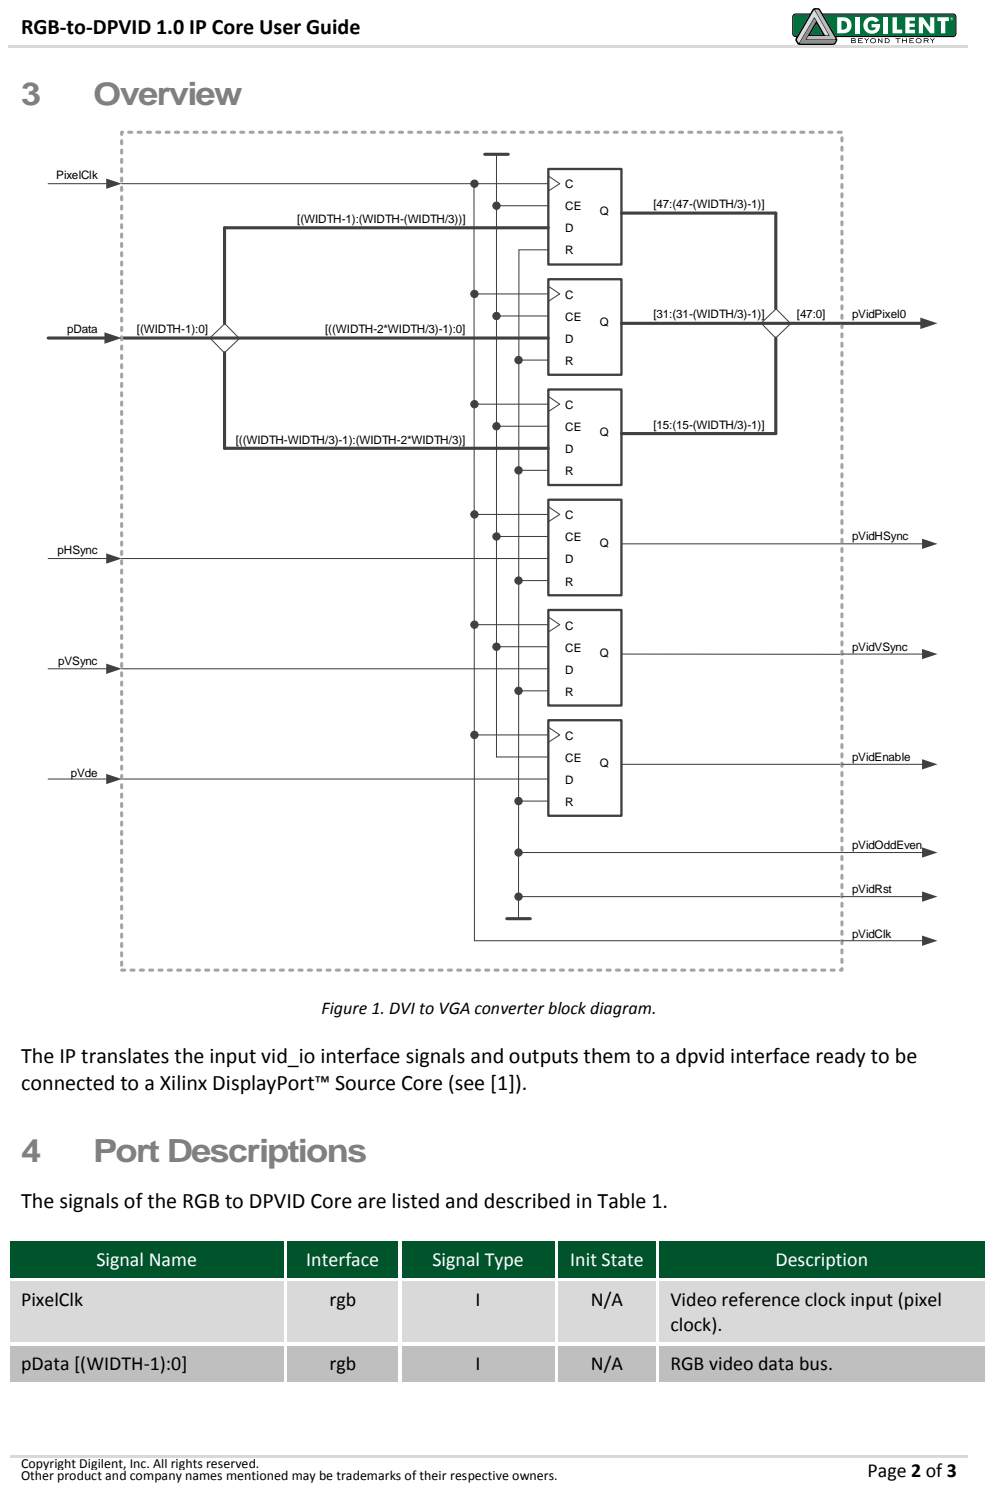
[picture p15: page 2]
Other product and company names mentioned may be trademarks of their respective owners.; Page 2 of 3; [((WIDTH-2*WIDTH/3)-1):0]; [47:(47-(WIDTH/3)-1)]; [31:(31-(WIDTH/3)-1)]; [15:(15-(WIDTH/3)-1)]; [(WIDTH-1):0]; PixelClk; pData; pHSync; pVSync; pVde; pVidPixel0; pVidHSync; pVidVSync; pVidEnable; pVidOddEven; pVidRst; pVidClk; 4 Port Descriptions; Signal Name; Interface; Signal Type; Init State; Description; rgb; Video reference clock input (pixel; clock).; pData [(WIDTH-1):0]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

RGB-to-DPVID 1.0 IP Core User Guide

[(WIDTH-1):(WIDTH-(WIDTH/3))]

[((WIDTH-WIDTH/3)-1):(WIDTH-2*WIDTH/3)]

Figure 1. DVI to VGA converter block diagram.

The IP translates the input vid_io interface signals and outputs them to a dpvid interface ready to be
connected to a Xilinx DisplayPort™ Source Core (see [1]).

The signals of the RGB to DPVID Core are listed and described in Table 1.

Copyright Digilent, Inc. All rights reserved.

RGB-to-DPVID 1.0 IP Core User Guide

Copyright Digilent, Inc. All rights reserved.
Other product and company names mentioned may be trademarks of their respective owners. | Page 3 of 3
pHSync | rgb | I | N/A | Horizontal synchronization video timing signal.
pVSync | rgb | I | N/A | Vertical synchronization video timing signal.
pVde | rgb | I | N/A | Video data valid: • 1 = Active video. • 0 = Blanking period.
pVidClk | dpvid | O | 0 | Forwarded PixelClk signal.
pVidPixel0 [47:0] | dpvid | O | zeros | Video data output.
pVidHSync | dpvid | O | 0 | Horizontal synchronization video timing signal.
pVidVSync | dpvid | O | 0 | Vertical synchronization video timing signal.
pVidEnable | dpvid | O | 0 | Video data qualifier: • 1 = Video data valid. • 0 = Video data not valid.
pVidOddEven | dpvid | O | 0 | Unused.
pVidRst | dpvid | O | 0 | Unused.

Table 1. Port descriptions.

## 5 Parameter Descriptions

The parameters of the RGB to DPVID Core are listed and described in Table 12 below.

Parameter Name | Range | Type | Default | Description
kDataWidth | 0 - 47 | integer | 24 | Sets the input video data bus width containing already the video components. It is limited at a maximum of 48 which is the limit of the dpvid-interface data signal input (see Table 3-3 of [1]).

Table 2. Parameter descriptions.

## 6 References

The following documents provide additional information on the subjects discussed:

1. Xilinx Inc., PG064: DisplayPort LogiCORE IP Product Guide, v6.0, April 1, 2015.

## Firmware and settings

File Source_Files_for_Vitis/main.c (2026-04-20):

// #include <stdint.h>
// #include <stdbool.h>

// #ifdef __cplusplus
// #ifndef _Bool
// #define _Bool bool
// #endif
// extern "C" {
// #endif

// #include "xparameters.h"
// #include "xstatus.h"
// #include "sleep.h"
// #include "xil_printf.h"
// #include "xil_types.h"
// #include "xil_cache.h"
// #include "xil_io.h"

// #include "xiicps.h"
// #include "xuartlite.h"

// #include "xaudioformatter.h"
// #include "xi2stx.h"
// #include "xiic.h"
// #include "xgpio.h"

// #ifdef __cplusplus
// }
// #endif

// /*
//  * ============================================================
//  * Top-level test selection
//  * Set exactly ONE of these to 1.
//  * ============================================================
//  */
// #define TEST_MOTOR                0
// #define TEST_I2C_BNO055           0
// #define TEST_SONAR_UART           0
// #define TEST_AUDIO_A4_TONE        0
// #define TEST_AUDIO_SINGLE_NOTE    0
// #define TEST_AUDIO_C_SCALE        0
// #define TEST_AUDIO_C_SCALE_UPDOWN 1

// #if (TEST_MOTOR + TEST_I2C_BNO055 + TEST_SONAR_UART + \
//      TEST_AUDIO_A4_TONE + TEST_AUDIO_SINGLE_NOTE + \
//      TEST_AUDIO_C_SCALE + TEST_AUDIO_C_SCALE_UPDOWN) != 1
// #error "Set exactly one TEST_* macro to 1"
// #endif

// /* ============================================================
//  * MOTOR TEST
//  * ============================================================
//  */
// #if TEST_MOTOR

// #ifndef XPAR_MOTOR_CTRL_4CH_0_BASEADDR
// #error "XPAR_MOTOR_CTRL_4CH_0_BASEADDR is not defined in xparameters.h"
// #endif

// #define MOTOR_BASE XPAR_MOTOR_CTRL_4CH_0_BASEADDR

// #define REG_CTRL   0x00U
// #define REG_PERIOD 0x04U
// #define REG_DUTY0  0x08U

// #define M0_EN      (1u << 0)
// #define M0_DIR     (1u << 4)
// #define M0_BRAKE   (1u << 8)

// static inline void motor_wr(unsigned offset, unsigned value)
// {
//     Xil_Out32(MOTOR_BASE + offset, value);
// }

// static void motor0_stop(void)
// {
//     motor_wr(REG_DUTY0, 0U);
//     motor_wr(REG_CTRL, 0U);
// }

// static void motor0_brake(void)
// {
//     motor_wr(REG_DUTY0, 0U);
//     motor_wr(REG_CTRL, M0_EN | M0_BRAKE);
// }

// static void motor0_forward(unsigned duty)
// {
//     motor_wr(REG_DUTY0, duty);
//     motor_wr(REG_CTRL, M0_EN);
// }

// static void motor0_reverse(unsigned duty)
// {
//     motor_wr(REG_DUTY0, duty);
//     motor_wr(REG_CTRL, M0_EN | M0_DIR);
// }

// int main(void)
// {
//     const unsigned period = 5000U;
//     const unsigned duty10 = 500U;
//     const unsigned duty20 = 1000U;

//     xil_printf("motor functional test start\r\n");
//     xil_printf("motor base = 0x%08X\r\n", (unsigned)MOTOR_BASE);

//     motor_wr(REG_PERIOD, period);
//     motor0_stop();
//     usleep(300000);

//     while (1) {
//         xil_printf("forward 10%%\r\n");
//         motor0_forward(duty10);
//         usleep(300000);

//         xil_printf("brake\r\n");
//         motor0_brake();
//         usleep(200000);

//         xil_printf("reverse 10%%\r\n");
//         motor0_reverse(duty10);
//         usleep(300000);

//         xil_printf("brake\r\n");
//         motor0_brake();
//         usleep(200000);

//         xil_printf("forward 20%%\r\n");
//         motor0_forward(duty20);
//         usleep(300000);

//         xil_printf("stop\r\n");
//         motor0_stop();
//         usleep(500000);
//     }

//     return 0;
// }

// /* ============================================================
//  * I2C BNO055 TEST
//  * ============================================================
//  */
// #elif TEST_I2C_BNO055

// #if !defined(XPAR_XIICPS_1_BASEADDR)
// #error "XPAR_XIICPS_1_BASEADDR is not defined in xparameters.h"
// #endif

// #define IIC_SCLK_RATE           50000U
// #define BNO055_I2C_ADDR         0x28U

// #define BNO055_CHIP_ID_REG      0x00U
// #define BNO055_PAGE_ID_REG      0x07U
// #define BNO055_ACC_DATA_X_LSB   0x08U
// #define BNO055_GYR_DATA_X_LSB   0x14U
// #define BNO055_UNIT_SEL_REG     0x3BU
// #define BNO055_OPR_MODE_REG     0x3DU
// #define BNO055_PWR_MODE_REG     0x3EU

// #define BNO055_CHIP_ID_VAL      0xA0U
// #define BNO055_PWR_NORMAL       0x00U
// #define BNO055_OPR_CONFIG       0x00U
// #define BNO055_OPR_AMG          0x07U

// static XIicPs Iic;

// static int wait_bus_idle(XIicPs *IicPtr)
// {
//     int timeout = 1000000;

//     while (XIicPs_BusIsBusy(IicPtr) && timeout > 0)
//         timeout--;

//     return (timeout > 0) ? XST_SUCCESS : XST_FAILURE;
// }

// static int i2c_write_reg(u8 reg, u8 value)
// {
//     u8 tx[2];
//     int status;

//     tx[0] = reg;
//     tx[1] = value;

//     status = XIicPs_MasterSendPolled(&Iic, tx, 2, BNO055_I2C_ADDR);
//     if (status != XST_SUCCESS)
//         return status;

//     return wait_bus_idle(&Iic);
// }

// static int i2c_read_bytes(u8 reg, u8 *rx, int len)
// {
//     int status;

//     status = XIicPs_SetOptions(&Iic, XIICPS_7_BIT_ADDR_OPTION | XIICPS_REP_START_OPTION);
//     if (status != XST_SUCCESS)
//         return status;

//     status = XIicPs_MasterSendPolled(&Iic, &reg, 1, BNO055_I2C_ADDR);
//     if (status != XST_SUCCESS) {
//         XIicPs_ClearOptions(&Iic, XIICPS_REP_START_OPTION);
//         return status;
//     }

//     status = XIicPs_MasterRecvPolled(&Iic, rx, len, BNO055_I2C_ADDR);

//     XIicPs_ClearOptions(&Iic, XIICPS_REP_START_OPTION);

//     if (status != XST_SUCCESS)
//         return status;

//     return wait_bus_idle(&Iic);
// }

// static int i2c_read_reg(u8 reg, u8 *value)
// {
//     return i2c_read_bytes(reg, value, 1);
// }

// static int16_t le16_to_s16(u8 lsb, u8 msb)
// {
//     return (int16_t)(((uint16_t)msb << 8) | (uint16_t)lsb);
// }

// static void print_fixed_2(const char *name, int32_t whole, int32_t frac, int negative)
// {
//     xil_printf("%s=%s%d.%02d", name, negative ? "-" : "", (int)whole, (int)frac);
// }

// static void print_accel_mps2(const char *name, int16_t raw)
// {
//     int32_t mag = raw;
//     int negative = 0;

//     if (mag < 0) {
//         negative = 1;
//         mag = -mag;
//     }

//     print_fixed_2(name, mag / 100, mag % 100, negative);
// }

// static void print_gyro_dps(const char *name, int16_t raw)
// {
//     int32_t mag = raw;
//     int negative = 0;
//     int32_t whole;
//     int32_t frac;

//     if (mag < 0) {
//         negative = 1;
//         mag = -mag;
//     }

//     whole = mag / 16;
//     frac  = ((mag % 16) * 100) / 16;

//     print_fixed_2(name, whole, frac, negative);
// }

// static int bno055_init(void)
// {
//     u8 chip_id = 0;
//     int status;
//     int tries;

//     usleep(800000);

//     for (tries = 0; tries < 10; tries++) {
//         status = i2c_read_reg(BNO055_CHIP_ID_REG, &chip_id);
//         if ((status == XST_SUCCESS) && (chip_id == BNO055_CHIP_ID_VAL))
//             break;
//         usleep(50000);
//     }

//     if (chip_id != BNO055_CHIP_ID_VAL) {
//         xil_printf("BNO055 chip ID read failed. Got 0x%02X\r\n", chip_id);
//         return XST_FAILURE;
//     }

//     xil_printf("BNO055 chip ID OK: 0x%02X\r\n", chip_id);

//     status = i2c_write_reg(BNO055_PAGE_ID_REG, 0x00U);
//     if (status != XST_SUCCESS)
//         return status;

//     status = i2c_write_reg(BNO055_OPR_MODE_REG, BNO055_OPR_CONFIG);
//     if (status != XST_SUCCESS)
//         return status;

//     usleep(25000);

//     status = i2c_write_reg(BNO055_PWR_MODE_REG, BNO055_PWR_NORMAL);
//     if (status != XST_SUCCESS)
//         return status;

//     usleep(10000);

//     status = i2c_write_reg(BNO055_UNIT_SEL_REG, 0x00U);
//     if (status != XST_SUCCESS)
//         return status;

//     usleep(10000);

//     status = i2c_write_reg(BNO055_OPR_MODE_REG, BNO055_OPR_AMG);
//     if (status != XST_SUCCESS)
//         return status;

//     usleep(20000);

//     xil_printf("BNO055 set to AMG mode\r\n");
//     return XST_SUCCESS;
// }

// static int i2c_controller_init(void)
// {
//     XIicPs_Config *cfg;
//     int status;

// #ifdef SDT
//     cfg = XIicPs_LookupConfig(XPAR_XIICPS_1_BASEADDR);
// #else
//     cfg = XIicPs_LookupConfig(XPAR_XIICPS_1_DEVICE_ID);
// #endif

//     if (cfg == NULL)
//         return XST_FAILURE;

//     status = XIicPs_CfgInitialize(&Iic, cfg, cfg->BaseAddress);
//     if (status != XST_SUCCESS)
//         return status;

//     status = XIicPs_SelfTest(&Iic);
//     if (status != XST_SUCCESS)
//         return status;

//     status = XIicPs_SetSClk(&Iic, IIC_SCLK_RATE);
//     if (status != XST_SUCCESS)
//         return status;

//     status = XIicPs_SetOptions(&Iic, XIICPS_7_BIT_ADDR_OPTION);
//     if (status != XST_SUCCESS)
//         return status;

//     return XST_SUCCESS;
// }

// int main(void)
// {
//     int status;
//     u8 acc_buf[6];
//     u8 gyr_buf[6];
//     int16_t ax, ay, az;
//     int16_t gx, gy, gz;

//     xil_printf("BNO055 I2C test start\r\n");
//     xil_printf("I2C1 base = 0x%08X\r\n", (unsigned)XPAR_XIICPS_1_BASEADDR);

//     status = i2c_controller_init();
//     if (status != XST_SUCCESS) {
//         xil_printf("I2C controller init failed\r\n");
//         while (1) {
//         }
//     }

//     status = bno055_init();
//     if (status != XST_SUCCESS) {
//         xil_printf("BNO055 init failed\r\n");
//         while (1) {
//         }
//     }

//     while (1) {
//         status = i2c_read_bytes(BNO055_ACC_DATA_X_LSB, acc_buf, 6);
//         if (status != XST_SUCCESS) {
//             xil_printf("Accel read failed\r\n");
//             usleep(200000);
//             continue;
//         }

//         status = i2c_read_bytes(BNO055_GYR_DATA_X_LSB, gyr_buf, 6);
//         if (status != XST_SUCCESS) {
//             xil_printf("Gyro read failed\r\n");
//             usleep(200000);
//             continue;
//         }

//         ax = le16_to_s16(acc_buf[0], acc_buf[1]);
//         ay = le16_to_s16(acc_buf[2], acc_buf[3]);
//         az = le16_to_s16(acc_buf[4], acc_buf[5]);

//         gx = le16_to_s16(gyr_buf[0], gyr_buf[1]);
//         gy = le16_to_s16(gyr_buf[2], gyr_buf[3]);
//         gz = le16_to_s16(gyr_buf[4], gyr_buf[5]);

//         print_accel_mps2("AX", ax);
//         xil_printf(" ");
//         print_accel_mps2("AY", ay);
//         xil_printf(" ");
//         print_accel_mps2("AZ", az);
//         xil_printf(" m/s^2 | ");

//         print_gyro_dps("GX", gx);
//         xil_printf(" ");
//         print_gyro_dps("GY", gy);
//         xil_printf(" ");
//         print_gyro_dps("GZ", gz);
//         xil_printf(" dps\r\n");

//         usleep(100000);
//     }

//     return 0;
// }

// /* ============================================================
//  * SONAR UART TEST
//  * ============================================================
//  */
// #elif TEST_SONAR_UART

// #ifndef XPAR_XUARTLITE_0_BASEADDR
// #error "XPAR_XUARTLITE_0_BASEADDR is not defined in xparameters.h"
// #endif

// #define SONAR_UART_BASEADDR XPAR_XUARTLITE_0_BASEADDR

// static XUartLite UartLite;

// static int uartlite_init(void)
// {
//     int status;

// #ifdef SDT
//     status = XUartLite_Initialize(&UartLite, SONAR_UART_BASEADDR);
// #else
//     status = XUartLite_Initialize(&UartLite, XPAR_UARTLITE_0_DEVICE_ID);
// #endif
//     if (status != XST_SUCCESS)
//         return status;

//     status = XUartLite_SelfTest(&UartLite);
//     if (status != XST_SUCCESS)
//         return status;

//     return XST_SUCCESS;
// }

// static int uartlite_get_byte(u8 *byte_out)
// {
//     unsigned int rx_count;

//     rx_count = XUartLite_Recv(&UartLite, byte_out, 1);
//     return (rx_count == 1U) ? 1 : 0;
// }

// static int is_digit_u8(u8 c)
// {
//     return (c >= '0' && c <= '9');
// }

// int main(void)
// {
//     int status;
//     u8 c = 0;
//     u8 d1 = 0, d2 = 0, d3 = 0;
//     int state = 0;
//     int inches;
//     int cm_x100;

//     xil_printf("MAXSONAR UART test start\r\n");
//     xil_printf("UARTLite base = 0x%08X\r\n", (unsigned int)SONAR_UART_BASEADDR);

//     status = uartlite_init();
//     if (status != XST_SUCCESS) {
//         xil_printf("UARTLite init failed\r\n");
//         while (1) {
//         }
//     }

//     xil_printf("UARTLite init OK\r\n");
//     xil_printf("Waiting for sonar frames...\r\n");

//     usleep(500000);

//     while (1) {
//         if (!uartlite_get_byte(&c)) {
//             usleep(1000);
//             continue;
//         }

//         switch (state) {
//         case 0:
//             if (c == 'R')
//                 state = 1;
//             break;

//         case 1:
//             if (is_digit_u8(c)) {
//                 d1 = c;
//                 state = 2;
//             } else if (c == 'R') {
//                 state = 1;
//             } else {
//                 state = 0;
//             }
//             break;

//         case 2:
//             if (is_digit_u8(c)) {
//                 d2 = c;
//                 state = 3;
//             } else if (c == 'R') {
//                 state = 1;
//             } else {
//                 state = 0;
//             }
//             break;

//         case 3:
//             if (is_digit_u8(c)) {
//                 d3 = c;
//                 state = 4;
//             } else if (c == 'R') {
//                 state = 1;
//             } else {
//                 state = 0;
//             }
//             break;

//         case 4:
//             if (c == '\r') {
//                 inches = (d1 - '0') * 100 + (d2 - '0') * 10 + (d3 - '0');
//                 cm_x100 = inches * 254;

//                 xil_printf("Range: %d in, %d.%02d cm\r\n",
//                            inches,
//                            cm_x100 / 100,
//                            cm_x100 % 100);
//             }
//             state = 0;
//             break;

//         default:
//             state = 0;
//             break;
//         }
//     }

//     return 0;
// }

// /* ============================================================
//  * AUDIO TESTS
//  * ============================================================
//  */
// #else

// #ifndef XPAR_XAUDIO_FORMATTER_0_BASEADDR
// #error "XPAR_XAUDIO_FORMATTER_0_BASEADDR is not defined in xparameters.h"
// #endif

// #ifndef XPAR_XI2STX_0_BASEADDR
// #error "XPAR_XI2STX_0_BASEADDR is not defined in xparameters.h"
// #endif

// #ifndef XPAR_XIIC_0_BASEADDR
// #error "XPAR_XIIC_0_BASEADDR is not defined in xparameters.h"
// #endif

// #ifndef XPAR_XGPIO_0_BASEADDR
// #error "XPAR_XGPIO_0_BASEADDR is not defined in xparameters.h"
// #endif

// #define CODEC_I2C_ADDR           0x1AU

// #define SAMPLE_RATE_HZ           48000U
// #define AUDIO_MCLK_HZ            12288000U

// #define AMP                      10000
// #define NOTE_DURATION_MS         500U
// #define GAP_DURATION_US          250000U

// #define NUM_CHANNELS             2U
// #define BYTES_PER_SAMPLE         2U
// #define FRAME_BYTES              (NUM_CHANNELS * BYTES_PER_SAMPLE)

// #define NOTE_FRAMES              ((SAMPLE_RATE_HZ * NOTE_DURATION_MS) / 1000U)
// #define NOTE_BYTES               (NOTE_FRAMES * FRAME_BYTES)

// #define AF_PERIODS               8U
// #define AF_BYTES_PER_PERIOD      (NOTE_BYTES / AF_PERIODS)

// #if (NOTE_BYTES % AF_PERIODS) != 0
// #error "NOTE_BYTES must divide evenly into AF_PERIODS"
// #endif

// #if (AF_BYTES_PER_PERIOD < 64) || (AF_BYTES_PER_PERIOD > (50 * 1024))
// #error "AF_BYTES_PER_PERIOD must be between 64 and 51200 bytes"
// #endif

// #define A4_FREQ_CENTI_HZ           44000U
// #define A4_NAME                    "A4"
// #define SINGLE_NOTE_FREQ_CENTI_HZ  26163U
// #define SINGLE_NOTE_NAME           "C4"

// static const uint32_t ScaleFreqCentiHz[] = {
//     26163U, 29366U, 32963U, 34923U, 39200U, 44000U, 49388U, 52325U
// };

// static const char *ScaleNames[] = {
//     "C4", "D4", "E4", "F4", "G4", "A4", "B4", "C5"
// };

// #define SCALE_NOTES ((uint32_t)(sizeof(ScaleFreqCentiHz) / sizeof(ScaleFreqCentiHz[0])))

// static int16_t AudioBuf[NOTE_FRAMES * NUM_CHANNELS] __attribute__((aligned(64)));

// static XAudioFormatter AudioFormatter;
// static XI2s_Tx I2sTx;
// static XIic AudioIic;
// static XGpio MuteGpio;

// static int mute_gpio_init(void)
// {
//     int status;

// #ifdef SDT
//     status = XGpio_Initialize(&MuteGpio, XPAR_XGPIO_0_BASEADDR);
// #else
//     status = XGpio_Initialize(&MuteGpio, XPAR_XGPIO_0_DEVICE_ID);
// #endif
//     if (status != XST_SUCCESS)
//         return status;

//     XGpio_SetDataDirection(&MuteGpio, 1, 0x0U);
//     XGpio_DiscreteWrite(&MuteGpio, 1, 0x0U);

//     return XST_SUCCESS;
// }

// static void codec_unmute(void)
// {
//     XGpio_DiscreteWrite(&MuteGpio, 1, 0x1U);
// }

// static void codec_mute(void)
// {
//     XGpio_DiscreteWrite(&MuteGpio, 1, 0x0U);
// }

// static int audio_iic_init(void)
// {
//     int status;

// #ifdef SDT
//     status = XIic_Initialize(&AudioIic, XPAR_XIIC_0_BASEADDR);
// #else
//     status = XIic_Initialize(&AudioIic, XPAR_XIIC_0_DEVICE_ID);
// #endif
//     if (status != XST_SUCCESS)
//         return status;

//     status = XIic_Start(&AudioIic);
//     if (status != XST_SUCCESS)
//         return status;

//     return XST_SUCCESS;
// }

// static int codec_write_reg(uint8_t reg, uint16_t value9)
// {
//     uint8_t buf[2];
//     int sent;

//     buf[0] = (uint8_t)((reg << 1) | ((value9 >> 8) & 0x1U));
//     buf[1] = (uint8_t)(value9 & 0xFFU);

//     sent = XIic_Send(AudioIic.BaseAddress, CODEC_I2C_ADDR, buf, 2, XIIC_STOP);
//     return (sent == 2) ? XST_SUCCESS : XST_FAILURE;
// }

// static int codec_init_ssm2603(void)
// {
//     int status;

//     status = codec_write_reg(15U, 0x000U);
//     if (status != XST_SUCCESS)
//         return status;

//     usleep(10000);

//     status = codec_write_reg(6U, 0x030U);
//     if (status != XST_SUCCESS)
//         return status;

//     status = codec_write_reg(0U, 0x017U);
//     if (status != XST_SUCCESS)
//         return status;

//     status = codec_write_reg(1U, 0x017U);
//     if (status != XST_SUCCESS)
//         return status;

//     status = codec_write_reg(2U, 0x079U);
//     if (status != XST_SUCCESS)
//         return status;

//     status = codec_write_reg(3U, 0x079U);
//     if (status != XST_SUCCESS)
//         return status;

//     status = codec_write_reg(4U, 0x010U);
//     if (status != XST_SUCCESS)
//         return status;

//     status = codec_write_reg(5U, 0x000U);
//     if (status != XST_SUCCESS)
//         return status;

//     status = codec_write_reg(7U, 0x002U);
//     if (status != XST_SUCCESS)
//         return status;

//     status = codec_write_reg(8U, 0x000U);
//     if (status != XST_SUCCESS)
//         return status;

//     usleep(100000);

//     status = codec_write_reg(9U, 0x001U);
//     if (status != XST_SUCCESS)
//         return status;

//     status = codec_write_reg(6U, 0x020U);
//     if (status != XST_SUCCESS)
//         return status;

//     usleep(10000);
//     return XST_SUCCESS;
// }

// static int i2s_tx_init(void)
// {
//     int status;
//     XI2stx_Config *cfg;

// #ifdef SDT
//     cfg = XI2s_Tx_LookupConfig(XPAR_XI2STX_0_BASEADDR);
// #else
//     cfg = XI2s_Tx_LookupConfig(XPAR_XI2STX_0_DEVICE_ID);
// #endif
//     if (cfg == NULL)
//         return XST_FAILURE;

//     status = XI2s_Tx_CfgInitialize(&I2sTx, cfg, cfg->BaseAddress);
//     if (status != XST_SUCCESS)
//         return status;

//     status = XI2s_Tx_SelfTest(&I2sTx);
//     if (status != XST_SUCCESS)
//         return status;

//     status = XI2s_Tx_SetSclkOutDiv(&I2sTx, AUDIO_MCLK_HZ, SAMPLE_RATE_HZ);
//     if (status != XST_SUCCESS)
//         return status;

//     status = XI2s_Tx_SetChMux(&I2sTx, XI2S_TX_CHID0, XI2S_TX_CHMUX_AXIS_01);
//     if (status != XST_SUCCESS)
//         return status;

//     XI2s_Tx_Enable(&I2sTx, TRUE);
//     return XST_SUCCESS;
// }

// static int audio_formatter_init(void)
// {
//     int status;
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
int main(void)
{
    int status;

    xil_printf("\r\n----------------------------------------\r\n");
    xil_printf("Audio Formatter + I2S TX selectable audio test\r\n");
    xil_printf("AF base   = 0x%08x\r\n", (uint32_t)XPAR_XAUDIO_FORMATTER_0_BASEADDR);
    xil_printf("I2S base  = 0x%08x\r\n", (uint32_t)XPAR_XI2STX_0_BASEADDR);
    xil_printf("IIC base  = 0x%08x\r\n", (uint32_t)XPAR_XIIC_0_BASEADDR);
    xil_printf("GPIO base = 0x%08x\r\n", (uint32_t)XPAR_XGPIO_0_BASEADDR);
    xil_printf("Buffer @  = 0x%08x\r\n", (uint32_t)(UINTPTR)AudioBuf);
    xil_printf("Buffer bytes     = %u\r\n", (uint32_t)AUDIO_BUF_BYTES);
    xil_printf("Max note time    = %u ms\r\n", (unsigned)MAX_NOTE_DURATION_MS);
    xil_printf("Periods          = %u\r\n", (uint32_t)AF_PERIODS);
    xil_printf("Default note time= %u ms\r\n", (unsigned)NOTE_DURATION_MS);
    xil_printf("Default mute gap = %u us\r\n", (unsigned)GAP_DURATION_US);

    Xil_ICacheEnable();
    Xil_DCacheEnable();

    status = mute_gpio_init();
    if (status != XST_SUCCESS) {
        xil_printf("Mute GPIO init failed\r\n");
        while (1) {
        }
    }
    codec_mute();

    status = audio_iic_init();
    if (status != XST_SUCCESS) {
        xil_printf("Audio IIC init failed\r\n");
        while (1) {
        }
    }

    status = codec_init_ssm2603();
    if (status != XST_SUCCESS) {
        xil_printf("Codec init failed\r\n");
        while (1) {
        }
    }

    status = i2s_tx_init();
    if (status != XST_SUCCESS) {
        xil_printf("I2S TX init failed\r\n");
        while (1) {
        }
    }

    status = audio_formatter_init();
    if (status != XST_SUCCESS) {
        xil_printf("Audio Formatter init failed\r\n");
        while (1) {
        }
    }

    status = run_audio_test();
    if (status != XST_SUCCESS) {
        codec_mute();
        xil_printf("Audio test failed\r\n");
        while (1) {
        }
    }

    codec_mute();
    xil_printf("Audio test done\r\n");
    xil_printf("----------------------------------------\r\n");

    while (1) {
    }

    return 0;
}

#endif

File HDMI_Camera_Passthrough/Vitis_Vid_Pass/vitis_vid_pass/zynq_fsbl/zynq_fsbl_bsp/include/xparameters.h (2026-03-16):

#ifndef XPARAMETERS_H   /* prevent circular inclusions */
#define XPARAMETERS_H   /* by using protection macros */

#define XPAR_XAXIVDMA_NUM_INSTANCES 1

/* Definitions for peripheral AXI_VDMA_0 */
#define XPAR_AXI_VDMA_0_COMPATIBLE "xlnx,axi-vdma-6.3"
#define XPAR_AXI_VDMA_0_BASEADDR 0x43000000
#define XPAR_AXI_VDMA_0_HIGHADDR 0x4300ffff
#define XPAR_AXI_VDMA_0_NUM_FSTORES 0x3
#define XPAR_AXI_VDMA_0_INCLUDE_MM2S 0x1
#define XPAR_AXI_VDMA_0_INCLUDE_MM2S_DRE 0x0
#define XPAR_AXI_VDMA_0_MM2S_DATA_WIDTH 0x40
#define XPAR_AXI_VDMA_0_INCLUDE_S2MM 0x1
#define XPAR_AXI_VDMA_0_INCLUDE_S2MM_DRE 0x0
#define XPAR_AXI_VDMA_0_S2MM_DATA_WIDTH 0x40
#define XPAR_AXI_VDMA_0_INCLUDE_SG 0x0
#define XPAR_AXI_VDMA_0_ENABLE_VIDPARAM_READS 0x1
#define XPAR_AXI_VDMA_0_FLUSH_FSYNC 0x1
#define XPAR_AXI_VDMA_0_FLUSH_ON_FSYNC 0x1
#define XPAR_AXI_VDMA_0_MM2S_LINEBUFFER_DEPTH 0x400
#define XPAR_AXI_VDMA_0_S2MM_LINEBUFFER_DEPTH 0x400
#define XPAR_AXI_VDMA_0_MM2S_GENLOCK_MODE 0x3
#define XPAR_AXI_VDMA_0_S2MM_GENLOCK_MODE 0x2
#define XPAR_AXI_VDMA_0_INCLUDE_INTERNAL_GENLOCK 0x1
#define XPAR_AXI_VDMA_0_S2MM_SOF_ENABLE 0x1
#define XPAR_AXI_VDMA_0_MM2S_TDATA_WIDTH 0x18
#define XPAR_AXI_VDMA_0_S2MM_TDATA_WIDTH 0x18
#define XPAR_AXI_VDMA_0_ENABLE_DEBUG_INFO_1 0x0
#define XPAR_AXI_VDMA_0_ENABLE_DEBUG_INFO_5 0x0
#define XPAR_AXI_VDMA_0_ENABLE_DEBUG_INFO_6 0x1
#define XPAR_AXI_VDMA_0_ENABLE_DEBUG_INFO_7 0x1
#define XPAR_AXI_VDMA_0_ENABLE_DEBUG_INFO_9 0x0
#define XPAR_AXI_VDMA_0_ENABLE_DEBUG_INFO_13 0x0
#define XPAR_AXI_VDMA_0_ENABLE_DEBUG_INFO_14 0x1
#define XPAR_AXI_VDMA_0_ENABLE_DEBUG_INFO_15 0x1
#define XPAR_AXI_VDMA_0_ENABLE_DEBUG_ALL 0x0
#define XPAR_AXI_VDMA_0_ADDRWIDTH 0x20
#define XPAR_AXI_VDMA_0_ENABLE_VERT_FLIP 0x0
#define XPAR_AXI_VDMA_0_INTERRUPTS 0x401e
#define XPAR_AXI_VDMA_0_INTERRUPTS_1 0x401f
#define XPAR_FABRIC_AXI_VDMA_0_INTR 30
#define XPAR_FABRIC_AXI_VDMA_0_INTR_1 31
#define XPAR_AXI_VDMA_0_INTERRUPT_PARENT 0xf8f01000

/* Canonical definitions for peripheral AXI_VDMA_0 */
#define XPAR_XAXIVDMA_0_BASEADDR 0x43000000
#define XPAR_FABRIC_XAXIVDMA_0_INTR 30
#define XPAR_XAXIVDMA_0_HIGHADDR 0x4300ffff
#define XPAR_XAXIVDMA_0_ADDRWIDTH 0x20
#define XPAR_XAXIVDMA_0_COMPATIBLE "xlnx,axi-vdma-6.3"
#define XPAR_XAXIVDMA_0_ENABLE_VIDPARAM_READS 0x1
#define XPAR_XAXIVDMA_0_ENABLE_DEBUG_INFO_1 0x0
#define XPAR_XAXIVDMA_0_ENABLE_DEBUG_INFO_5 0x0
#define XPAR_XAXIVDMA_0_ENABLE_DEBUG_INFO_6 0x1
#define XPAR_XAXIVDMA_0_ENABLE_DEBUG_INFO_7 0x1
#define XPAR_XAXIVDMA_0_ENABLE_DEBUG_INFO_9 0x0
#define XPAR_XAXIVDMA_0_ENABLE_DEBUG_INFO_13 0x0
#define XPAR_XAXIVDMA_0_ENABLE_DEBUG_INFO_14 0x1
#define XPAR_XAXIVDMA_0_ENABLE_DEBUG_INFO_15 0x1
#define XPAR_XAXIVDMA_0_ENABLE_DEBUG_ALL 0x0
#define XPAR_XAXIVDMA_0_ENABLE_VERT_FLIP 0x0
#define XPAR_XAXIVDMA_0_FLUSH_FSYNC 0x1
#define XPAR_XAXIVDMA_0_FLUSH_ON_FSYNC 0x1
#define XPAR_XAXIVDMA_0_INCLUDE_MM2S 0x1
#define XPAR_XAXIVDMA_0_INCLUDE_MM2S_DRE 0x0
#define XPAR_XAXIVDMA_0_INCLUDE_S2MM 0x1
#define XPAR_XAXIVDMA_0_INCLUDE_S2MM_DRE 0x0
#define XPAR_XAXIVDMA_0_INCLUDE_SG 0x0
#define XPAR_XAXIVDMA_0_INCLUDE_INTERNAL_GENLOCK 0x1
#define XPAR_XAXIVDMA_0_INTERRUPTS 0x401e
#define XPAR_XAXIVDMA_0_INTERRUPT_PARENT 0xf8f01000
#define XPAR_XAXIVDMA_0_MM2S_DATA_WIDTH 0x40
#define XPAR_XAXIVDMA_0_MM2S_LINEBUFFER_DEPTH 0x400
#define XPAR_XAXIVDMA_0_MM2S_GENLOCK_MODE 0x3
#define XPAR_XAXIVDMA_0_MM2S_TDATA_WIDTH 0x18
#define XPAR_XAXIVDMA_0_NUM_FSTORES 0x3
#define XPAR_XAXIVDMA_0_S2MM_DATA_WIDTH 0x40
#define XPAR_XAXIVDMA_0_S2MM_LINEBUFFER_DEPTH 0x400
#define XPAR_XAXIVDMA_0_S2MM_GENLOCK_MODE 0x2
#define XPAR_XAXIVDMA_0_S2MM_SOF_ENABLE 0x1
#define XPAR_XAXIVDMA_0_S2MM_TDATA_WIDTH 0x18

#define XPAR_XCLK_WIZ_NUM_INSTANCES 1

/* Definitions for peripheral VIDEO_DYNCLK */
#define XPAR_VIDEO_DYNCLK_COMPATIBLE "xlnx,clk-wiz-6.0"
#define XPAR_VIDEO_DYNCLK_BASEADDR 0x43c00000
#define XPAR_VIDEO_DYNCLK_HIGHADDR 0x43c0ffff
#define XPAR_VIDEO_DYNCLK_ENABLE_CLOCK_MONITOR 0x0
#define XPAR_VIDEO_DYNCLK_ENABLE_USER_CLOCK0 0x0
#define XPAR_VIDEO_DYNCLK_ENABLE_USER_CLOCK1 0x0
#define XPAR_VIDEO_DYNCLK_ENABLE_USER_CLOCK2 0x0
#define XPAR_VIDEO_DYNCLK_ENABLE_USER_CLOCK3 0x0
#define XPAR_VIDEO_DYNCLK_REF_CLK_FREQ 0x64
#define XPAR_VIDEO_DYNCLK_USER_CLK_FREQ0 0x64
#define XPAR_VIDEO_DYNCLK_USER_CLK_FREQ1 0x64
#define XPAR_VIDEO_DYNCLK_USER_CLK_FREQ2 0x64
#define XPAR_VIDEO_DYNCLK_USER_CLK_FREQ3 0x64
#define XPAR_VIDEO_DYNCLK_PRECISION 0x1
#define XPAR_VIDEO_DYNCLK_ENABLE_PLL0 0x0
#define XPAR_VIDEO_DYNCLK_ENABLE_PLL1 0x0
#define XPAR_VIDEO_DYNCLK_PRIM_IN_FREQ 0x64
#define XPAR_VIDEO_DYNCLK_NUM_OUT_CLKS 0x1
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

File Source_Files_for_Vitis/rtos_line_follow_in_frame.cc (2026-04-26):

#include <stdint.h>
#include <stdbool.h>

extern "C" {
#include "../assert_filename_fix.h"
#include "xparameters.h"
#include "xstatus.h"
#include "xil_printf.h"
#include "xil_types.h"
#include "xil_io.h"
#include "xil_cache.h"
#include "sleep.h"
#include "xiicps.h"
#include "xuartlite.h"
#include "FreeRTOS.h"
#include "task.h"
#include "queue.h"
}

#include "../xparams_compat.h"
#include "../platform/platform.h"
#include "../ov5640/OV5640.h"
#include "../ov5640/ScuGicInterruptController.h"
#include "../ov5640/PS_GPIO.h"
#include "../ov5640/AXI_VDMA.h"
#include "../ov5640/PS_IIC.h"
#include "../hdmi/VideoOutput.h"
#include "../MIPI_D_PHY_RX_v1_0/src/MIPI_D_PHY_RX.h"
#include "../MIPI_CSI_2_RX_v1_0/src/MIPI_CSI_2_RX.h"

using namespace digilent;

namespace {

/* ============================================================
 * Camera / video pipeline defines
 * ============================================================ */
#define IRPT_CTL_DEVID          XPAR_PS7_SCUGIC_0_DEVICE_ID
#define GPIO_DEVID              XPAR_PS7_GPIO_0_DEVICE_ID
#define GPIO_IRPT_ID            XPAR_PS7_GPIO_0_INTR
#define CAM_I2C_DEVID           XPAR_PS7_I2C_0_DEVICE_ID
#define CAM_I2C_IRPT_ID         XPAR_PS7_I2C_0_INTR
#define VDMA_DEVID              XPAR_AXIVDMA_0_DEVICE_ID
#define VDMA_MM2S_IRPT_ID       XPAR_FABRIC_AXI_VDMA_0_MM2S_INTROUT_INTR
#define VDMA_S2MM_IRPT_ID       XPAR_FABRIC_AXI_VDMA_0_S2MM_INTROUT_INTR
#define DDR_BASE_ADDR           XPAR_DDR_MEM_BASEADDR
#define MEM_BASE_ADDR           (DDR_BASE_ADDR + 0x0A000000U)
#define GAMMA_BASE_ADDR         XPAR_AXI_GAMMACORRECTION_0_BASEADDR

#define FRAME_W                 1920
#define FRAME_H                 1080
#define BYTES_PER_PIXEL         3
#define FRAME_STRIDE            (FRAME_W * BYTES_PER_PIXEL)
#define FRAME_SIZE_BYTES        (FRAME_STRIDE * FRAME_H)
#define FRAME0_ADDR             (MEM_BASE_ADDR + 0U * FRAME_SIZE_BYTES)
#define FRAME1_ADDR             (MEM_BASE_ADDR + 1U * FRAME_SIZE_BYTES)
#define FRAME2_ADDR             (MEM_BASE_ADDR + 2U * FRAME_SIZE_BYTES)

/* If your pipeline stores pixels as BGR instead of RGB, flip this to 1. */
#define PIXEL_ORDER_BGR         0

/* ============================================================
 * Motor control IP (same reg map as square-path example)
 *   enable bits: [3:0], direction bits: [7:4], brake bits: [11:8]
 *   Channels 0,1 = LEFT pair; channels 2,3 = RIGHT pair.
 * ============================================================ */
#ifndef XPAR_MOTOR_CTRL_4CH_0_BASEADDR
#error "XPAR_MOTOR_CTRL_4CH_0_BASEADDR is not defined"
#endif
#define MOTOR_BASE              XPAR_MOTOR_CTRL_4CH_0_BASEADDR
#define REG_CTRL                0x00U
#define REG_PERIOD              0x04U
#define REG_DUTY0               0x08U
#define REG_DUTY1               0x0CU
#define REG_DUTY2               0x10U
#define REG_DUTY3               0x14U
#define MOTOR_EN_BIT(ch)        (1u << (ch))
#define MOTOR_DIR_BIT(ch)       (1u << (4u + (ch)))
#define MOTOR_BRAKE_BIT(ch)     (1u << (8u + (ch)))

#define LEFT_FORWARD_DIR_TRUE   0
#define RIGHT_FORWARD_DIR_TRUE  1

/* ============================================================
 * PS I2C1 / BNO055 (telemetry only; line-following uses camera)
 * ============================================================ */
#ifndef XPAR_XIICPS_1_BASEADDR
#error "XPAR_XIICPS_1_BASEADDR is not defined"
#endif
#define SENSOR_I2C_SCLK_HZ      50000U
#define BNO055_I2C_ADDR         0x28U
#define BNO055_CHIP_ID_REG      0x00U
#define BNO055_PAGE_ID_REG      0x07U
#define BNO055_ACC_DATA_X_LSB   0x08U
#define BNO055_GYR_DATA_X_LSB   0x14U
#define BNO055_UNIT_SEL_REG     0x3BU
#define BNO055_OPR_MODE_REG     0x3DU
#define BNO055_PWR_MODE_REG     0x3EU
#define BNO055_CHIP_ID_VAL      0xA0U
#define BNO055_PWR_NORMAL       0x00U
#define BNO055_OPR_CONFIG       0x00U
#define BNO055_OPR_AMG          0x07U

/* ============================================================
 * Sonar UART
 * ============================================================ */
#ifndef XPAR_XUARTLITE_0_BASEADDR
#error "XPAR_XUARTLITE_0_BASEADDR is not defined"
#endif
#define SONAR_UART_BASEADDR     XPAR_XUARTLITE_0_BASEADDR

/* ============================================================
 * Line-following / vision tuning knobs
 * ============================================================ */
/* ROI = top band of the frame because the camera is mounted upside down.
 * In the rotated image, the floor region nearest the robot appears at the top. */
#define ROI_Y_TOP               0       /* 0..359 = top 360 rows */
#define ROI_Y_BOTTOM            359
#define ROI_STRIDE_X            24      /* sample every Nth column */
#define ROI_STRIDE_Y            12      /* sample every Nth row */

/* Brightness threshold for classifying a pixel as line.
 * Luma = (R + 2G + B) >> 2  (range 0..255)
 * For DARK line on LIGHT floor: LINE_IS_DARK=1, LINE_LUMA_THRESH=80.
 * For LIGHT line on DARK floor: LINE_IS_DARK=0, LINE_LUMA_THRESH=160. */
#define LINE_IS_DARK            1
#define LINE_LUMA_THRESH        80

/* Minimum line-pixel count for detection to be considered valid. */
#define MIN_LINE_PIXELS         30
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

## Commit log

2026-03-16 added video passthrough to hdmi
    [PmodDHB1_MotorFeedback_0_0.xml]
2026-03-23 PCB Files
    Wireless Charging Station and Main Robot PCB
    [ERN.PcbLib, ERN.SchLib, ERN_Main.PrjPcb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]
2026-03-23 Changed PCB File Structure
    Moved libraries
    [ERN_Main.PrjPcb, WirelessChargerTx.PrjPcb, WirelessChargerTx.SchDoc]
2026-03-26 Schematic Additions
    Audio AB Amp, Load Switches for ESCs, Charger IC
    [ERN_Main.PrjPcb, ERN_Main.SchDoc, ERN_Main_2.SchDoc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]
2026-03-30 Schematics Actually Finished
    All footprints in, all that needs to be done is routing
    [ERN_Main.PrjPcb, ERN_Main.SchDoc, ERN_MainPCB.PcbDoc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]
2026-03-30 PCB Update
    Main PCB Update, needs more routing and placement
    [ERN_Main.SchDoc, ERN_MainPCB.PcbDoc, ERN_MainPower.SchDoc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]
2026-04-07 Finished Power Board Schematic
    Done
    [ERN_Main.SchDoc, ERN_MainPCB.PcbDoc, ERN_MainPower.PcbDoc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]
2026-04-07 Added Motor Drivers, Changed Schematics
    Added Toshiba Handybook
    [ERN_Main.SchDoc, ERN_MainPower.SchDoc, ERN_MainPowerV2.SchDoc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]
2026-04-07 Schematic Changes + Began PCBs
    Added a bunch of connectors, hooked up motor drivers, changed audio circuit input, a bunch of other stuff,
    [ERN_Main.SchDoc, ERN_MainPCB.PcbDoc, ERN_MainPowerV2.PcbDoc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]
2026-04-07 PCBs laid out, just gotta route
    Still need to lay out buck boost converter
    [ERN_Main.SchDoc, ERN_MainPCB.PcbDoc, ERN_MainPowerV2.PcbDoc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]
2026-04-08 Finished Layout
    Layout for main power and SoC PCBs finished, now to do routing
    [ERN_Main.SchDoc, ERN_MainPCB.PcbDoc, ERN_MainPowerV2.PcbDoc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]
2026-04-08 Finished Power Board
    Ready to order after double checking everything
    [ERN_MainPowerV2.PcbDoc, ERN_MainPowerV2.SchDoc]
2026-04-08 SoC Peripherals PCB Finished
    Ready to manufacture (first get rid of silk screen errors though)
    [ERN_Main.SchDoc, ERN_MainPCB.PcbDoc]
2026-04-08 Final DRC-passed ERN Main and Power PCBs
    Check over and order
    [ERN_MainPCB.PcbDoc, ERN_MainPowerV2.PcbDoc, ERN_MainPowerV2.SchDoc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]
2026-04-12 Final PCBs
    Done, ordered
    [ERN_Main.PrjPcb, ERN_Main.SchDoc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]
2026-04-20 added upside down camera stuff

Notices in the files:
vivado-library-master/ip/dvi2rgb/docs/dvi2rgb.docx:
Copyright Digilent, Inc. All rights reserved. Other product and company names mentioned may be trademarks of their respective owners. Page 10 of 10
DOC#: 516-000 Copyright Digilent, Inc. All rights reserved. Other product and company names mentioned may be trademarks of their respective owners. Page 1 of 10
